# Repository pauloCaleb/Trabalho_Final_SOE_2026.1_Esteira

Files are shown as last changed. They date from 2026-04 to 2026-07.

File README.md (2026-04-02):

## IDENTIFICAÇÃO DOS ESTUDANTES AUTORES
- Felipe de Castro Quixabeira -  231026812
- Paulo Caleb Fernandes da Silva - 211062820 

----
## ORIENTAÇÕES DO PLANO DE ENSINO

#### Projeto Final

Os alunos formarão duplas para montar um projeto final de maior dificuldade, cobrindo os tópicos vistos em sala de aula.

Os projetos serão propostos pelos alunos, e deverá ser apresentado:
- Um protótipo em funcionamento  
- Um relatório no formato científico (formatação IEEE)

#### Estrutura do Relatório

- **Resumo (1 ponto)**  
  Apresentar o projeto de forma geral e em poucas palavras.

- **Introdução (1 ponto)**  
  Descrição do problema a ser resolvido e revisão bibliográfica do assunto.

- **Desenvolvimento (5 pontos)**  
  Solução com justificativa baseada em fundamentos teóricos. Deve conter:

  - **Descrição do hardware (2 pontos)**  
    - BOM (*Bill of Materials*)  
    - Montagem (diagrama de blocos, esquemático e descrição textual)

  - **Descrição do software (3 pontos)**  
    - Apresentação e justificativa do algoritmo desenvolvido  
    - Explicação textual do funcionamento (fluxogramas ou pseudocódigo)  
    - **Importante:** não consiste em replicar o código  
    - O código deve ser incluído como **apêndice**

- **Resultados (2 pontos)**  
  - Experimentos para validar o projeto  
  - Análise crítica dos resultados esperados e obtidos  
  - Discussão de possíveis causas para divergências

- **Conclusão (1 ponto)**  
  Retomar sucintamente:
  - Problema  
  - Solução  
  - Resultados obtidos  

----

### Pontos de Controle (PC)

Os pontos de controle são prévias do projeto final.

> ⚠️ Cada dia de atraso resulta em **-0,5 pontos** na nota do respectivo ponto de controle.

#### PC1 — Proposta do Projeto
- Apresentação do tema escolhido  
- Definição do problema  
- Pesquisa (produtos existentes, artigos, etc.)  
- Texto contendo:
  - Introdução  
  - Justificativa  
  - Objetivos  
  - Requisitos  
  - Benefícios  
  - Revisão bibliográfica  

----

#### PC2 — Funcionamento Básico
- Conectar partes fundamentais ao Raspberry Pi  
  - Exemplos: GPS, sensores, e-mail, câmera, reconhecimento facial  
- Demonstrar funcionamento individual de cada parte  
- Permitido uso de linguagens interpretadas (Python, Octave, etc.)

**Texto:**
- Descrição de hardware  
- Descrição de software  
- Resultados obtidos  

----

#### PC3 — Refinamento do Protótipo
- Conectar todas as partes fundamentais  
- Acrescentar recursos de sistema:
  - Múltiplos processos e threads  
  - Pipes  
  - Sinais  
  - Semáforos  
  - Mutex  

- Desenvolvimento em **C e/ou C++**

**Texto:**
- Atualização de hardware  
- Atualização de software  
- Resultados  

----

#### PC4 — Refinamento Avançado
- Conectar todas as partes fundamentais  
- Acrescentar recursos avançados:
  - Linux em tempo real  

- Desenvolvimento em **C e/ou C++**

**Texto:**
- Atualização de hardware  
- Atualização de software  
- Resultados  

----

### Analogia: Quebra-cabeça

- **PC1:** Escolha do quebra-cabeça  
- **PC2:** Disposição das peças  
- **PC3:** Montagem  
- **PC4:** Montagem (refinamento)  

----

### Observações Importantes

- Todos os relatórios devem ser enviados via **Moodle**  
- Em caso de cópia (total ou parcial):  
  > ❌ Nota **ZERO**

----

### Template IEEE

Disponível em:  
👉 https://www.overleaf.com/read/djkphgstpqsh#36c54d

---
## DOCUMENTO FINAL NO OVERLEAF (em produção)

Link: https://www.overleaf.com/read/gpjtpbhxbqqf#979b82

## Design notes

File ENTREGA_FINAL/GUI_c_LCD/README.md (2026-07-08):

# Esteira Separadora — Guia de Utilização

Sistema de controle em C para **Raspberry Pi 3B**, responsável pela comunicação
com o firmware STM32G070 que governa a esteira separadora via UART.

---

## Requisitos de Hardware

| Componente | Detalhe |
|---|---|
| Raspberry Pi 3B | UART primária habilitada (`/dev/ttyS0`) |
| STM32G070 | Conectado aos pinos GPIO 14 (TX) e 15 (RX) do RPi |
| Câmera USB | Compatível com V4L2, índice 0 = `/dev/video0` |
| Nível lógico | STM32 opera em 3,3 V — mesmo nível do RPi, sem conversor |

> **Atenção:** Desabilite o console serial do RPi antes de usar.
> Caso contrário o Linux usará `/dev/ttyS0` como TTY de console e o
> programa receberá lixo na UART.

---

## Configuração da UART no Raspberry Pi

1. Execute `sudo raspi-config`
2. Acesse **Interface Options → Serial Port**
3. Responda **Não** para "login shell over serial"
4. Responda **Sim** para "serial port hardware enabled"
5. Reinicie o RPi

Verifique que o dispositivo existe:

```bash
ls -l /dev/ttyS0
```

---

## Dependências

```bash
sudo apt update
sudo apt install libopencv-dev libzbar-dev libgpiod-dev
```

---

## Compilação

```bash
make
```

Binário gerado: `./esteira`

Para limpar os objetos:

```bash
make clean
```

---

## Uso

```
./esteira [opções]

  -p <porta>    Porta serial     (padrão: /dev/ttyS0)
  -b <baud>     Baud rate        (padrão: 115200)
  -c <índice>   Índice da câmera (padrão: 0)
  -t <ms>       Timeout QR em ms (padrão: 30000 | 0 = sem limite)
  -m <1|2|3>    Modo direto: 1=FSM, 2=DEBUG, 3=HMI (pula menu interativo)
  -h            Exibe esta ajuda
```

### Exemplos

```bash
# Inicialização padrão — exibe menu de seleção de modo
./esteira

# Modo FSM direto, câmera índice 1, timeout de 20 s
./esteira -m 1 -c 1 -t 20000

# Modo DEBUG direto
./esteira -m 2

# Modo HMI direto (display LCD + botões START/STOP)
./esteira -m 3

# Baud rate diferente (altere também no firmware STM32)
./esteira -b 9600
```

Atalhos do Makefile:

```bash
make run        # compila e abre menu de seleção
make run-fsm    # compila e inicia direto no modo FSM
make run-dbg    # compila e inicia direto no modo DEBUG
make run-hmi    # compila e inicia direto no modo HMI
```

---

## Modos de Operação

### Modo FSM (1) — Operação Autônoma

O programa aguarda eventos do STM32 e responde automaticamente:

```
STM32 → OBJ_DETECTED   Objeto entrou na esteira
STM32 → CLSS_REQUEST   Objeto chegou sob a câmera
RPi   → lê QR code     Classifica destino (Rota A ou B)
RPi   → ROUTE_A_SEND   Envia rota ao STM32
STM32 → ROUTE_A_OK     Confirma entrega — ciclo reinicia
```

Encerre com **Ctrl+C**.

### Modo DEBUG (2) — Controle Manual

Menu interativo no terminal para acionar cada atuador individualmente.
Útil para testes de bancada.

| Tecla | Ação |
|---|---|
| `1` | Flash ON |
| `2` | Flash OFF |
| `3` | Cancela abrir |
| `4` | Cancela fechar |
| `5` | Motor engajar |
| `6` | Motor livre |
| `7` | Direção frente |
| `8` | Direção trás |
| `9` | Enviar N passos |
| `t` | Toggle DEBUG/FSM no STM32 |
| `r` | SW Reset STM32 (pede confirmação) |
| `q` | Sair |

### Modo HMI (3) — Display LCD + Botões START/STOP + Buzzer

Interface física para operação sem terminal: um display LCD 2004A
(I2C) mostra o status da esteira e os contadores de objetos entregues
em cada rota; um botão START e um botão STOP comandam a operação; um
buzzer reforça os alertas visuais do display.

```
[Tela de espera]  "Aperte START"  (mostra contadores A/B)
        │
        ▼ START pressionado
  Inicializa a câmera
        │
        ▼ sucesso
  Handshake com o STM32
        │
        ▼ sucesso
[Operação autônoma — mesma máquina de estados do Modo FSM,
 status + contadores no LCD]
        │
        │  START pressionado durante a operação → zera contadores A/B
        │
        │  falha na leitura do QR → alerta "QR nao identificado /
        │  Libere a esteira!" (backlight + buzzer piscando, sem
        │  timeout) até o operador confirmar com START
        │       │
        │       ▼ START (confirma o alerta)
        │  Reset do STM32 + reenvio do handshake, aguardado sem
        │  timeout fixo (backlight + buzzer continuam piscando)
        │  até o STM32 responder espontaneamente quando os sensores
        │  da esteira ficarem livres
        │       │
        │       ▼ handshake concluído
        │  Retoma a operação autônoma, contadores preservados
        │
        ▼ STOP pressionado (em qualquer estado da operação, inclusive
          durante os alertas acima)
  SW Reset no STM32 + volta para [Tela de espera]
```

O handshake **não** ocorre ao entrar no modo HMI — só é disparado ao
pressionar START, permitindo que o sistema fique ocioso por tempo
indefinido na tela de espera. Ao pressionar START, a câmera é
inicializada primeiro; o handshake com o STM32 só é disparado depois
dela estar pronta, garantindo que a operação autônoma só comece com
todo o hardware necessário já inicializado.

O display mostra, tanto na tela de espera quanto durante a operação,
os contadores de objetos entregues em cada rota (`A:<n> B:<n>`). Eles
persistem entre ciclos e só são zerados ao pressionar **START enquanto
o sistema está em operação**, sem afetar o ciclo em andamento. O botão
**STOP** mantém uma única função: encerrar a operação e voltar à tela
de espera, a partir de qualquer estado.

Se a leitura do QR falhar (timeout ou erro), o display mostra o aviso
"QR nao identificado" e instrui o operador a liberar a esteira; o
backlight e o buzzer piscam em sincronia, sem prazo definido, até o
operador confirmar com START. A confirmação reseta o STM32 e reenvia
o handshake; como o firmware do STM32 só responde ao handshake de
forma espontânea quando os sensores da esteira estão livres, o
Raspberry Pi aguarda essa resposta sem impor um timeout fixo — o
display permanece piscando durante toda a espera, e STOP cancela a
qualquer momento. Se o STM32 responder com erro de protocolo nesse
processo, o programa retorna à tela de espera.

Hardware esperado (ajustável em `hmi.h`):

| Componente | Padrão | Define em hmi.h |
|---|---|---|
| Display LCD 2004A (PCF8574) | `/dev/i2c-1`, endereço `0x27` | `HMI_I2C_DEVICE`, `HMI_LCD_I2C_ADDR` |
| Botão START | `gpiochip0`, linha 17 (GPIO17) | `HMI_BTN_START_LINE` |
| Botão STOP | `gpiochip0`, linha 27 (GPIO27) | `HMI_BTN_STOP_LINE` |
| Buzzer (saída) | `gpiochip0`, linha 23 (GPIO23) | `HMI_BUZZER_LINE` |
| Debounce (software) | 30 ms | `HMI_BTN_DEBOUNCE_MS` |

Os botões usam pull-up **externo** (nível lógico 0 = pressionado); o
GPIO do RPi é configurado sem bias interno para não competir com o
pull-up do circuito. O buzzer é uma saída digital simples (nível 1 =
ligado); se a linha não abrir, o modo HMI segue funcionando
normalmente e os alertas ficam apenas com o backlight piscando.

Ctrl+C encerra o modo HMI a partir de qualquer estado (inclusive
durante os alertas) e exibe no display a mensagem final:

```
PROGRAMA ENCERRADO
Reinicie pelo
terminal
```

Como o controlador HD44780 retém o conteúdo exibido sem energização
contínua, essa mensagem permanece visível no display mesmo após o
processo ser encerrado.

---

## Formato do QR Code

O QR deve conter o campo `Destino:` com o byte de rota em hexadecimal:

```
Nome da Peca: Parafuso M6
Destino: 0xAADA
```

`0xDA` → Rota A  
`0xDB` → Rota B  

O parser também aceita tokens isolados `0xDA` / `0xDB` em qualquer
posição do texto do QR.

---

## Saída no Terminal

Todas as mensagens seguem o formato:

```
HH:MM:SS.mmm  [CATEGORIA]  mensagem
```

| Categoria | Cor | Conteúdo |
|---|---|---|
| `[UART TX]` | Ciano | Frames enviados ao STM32 com bytes hex |
| `[UART RX]` | Verde | Frames recebidos do STM32 com bytes hex |
| `[FSM ]` | Azul | Transições de estado e pipeline visual |
| `[CAM ]` | Magenta | Eventos de câmera e leitura de QR |
| `[DBG ]` | Amarelo | Ações do modo debug |
| `[SYS ]` | Branco | Sistema: serial, threads, handshake |
| `[ERR ]` | Vermelho | Erros de protocolo ou hardware |

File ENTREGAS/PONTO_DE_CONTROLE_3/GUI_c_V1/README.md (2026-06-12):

# Esteira Separadora — Guia de Utilização

Sistema de controle em C para **Raspberry Pi 3B**, responsável pela comunicação
com o firmware STM32G070 que governa a esteira separadora via UART.

---

## Requisitos de Hardware

| Componente | Detalhe |
|---|---|
| Raspberry Pi 3B | UART primária em `/dev/ttyS0` |
| STM32G070 | Conectado aos pinos GPIO 14 (TX) e 15 (RX) do RPi |
| Câmera USB | Compatível com V4L2, índice 0 = `/dev/video0` |
| Nível lógico | STM32 opera em 3,3 V — mesmo nível do RPi, sem conversor |

---

## Dependências

```bash
sudo apt update
sudo apt install libopencv-dev libzbar-dev
```

---

## Compilação

```bash
make
```

Binário gerado: `./esteira`

Para limpar os objetos:

```bash
make clean
```

---

## Uso

```
./esteira [opções]

  -p <porta>    Porta serial     (padrão: /dev/ttyS0)
  -b <baud>     Baud rate        (padrão: 115200)
  -c <índice>   Índice da câmera (padrão: 0)
  -t <ms>       Timeout QR em ms (padrão: 30000 | 0 = sem limite)
  -m <1|2>      Modo direto: 1=FSM, 2=DEBUG (pula menu interativo)
  -h            Exibe esta ajuda
```

### Exemplos

```bash
# Inicialização padrão — exibe menu de seleção de modo
./esteira

# Modo FSM direto, câmera índice 1, timeout de 20 s
./esteira -m 1 -c 1 -t 20000

# Modo DEBUG direto
./esteira -m 2

# Baud rate diferente (altere também no firmware STM32)
./esteira -b 9600
```

Atalhos do Makefile:

```bash
make run        # compila e abre menu de seleção
make run-fsm    # compila e inicia direto no modo FSM
make run-dbg    # compila e inicia direto no modo DEBUG
```

---

## Modos de Operação

### Modo FSM (1) — Operação Autônoma

O programa aguarda eventos do STM32 e responde automaticamente:

```
STM32 → OBJ_DETECTED   Objeto entrou na esteira
STM32 → CLSS_REQUEST   Objeto chegou sob a câmera
RPi   → lê QR code     Classifica destino (Rota A ou B)
RPi   → ROUTE_A_SEND   Envia rota ao STM32
STM32 → ROUTE_A_OK     Confirma entrega — ciclo reinicia
```

Encerre com **Ctrl+C**.

### Modo DEBUG (2) — Controle Manual

Menu interativo no terminal para acionar cada atuador individualmente.
Útil para testes de bancada.

| Tecla | Ação |
|---|---|
| `1` | Flash ON |
| `2` | Flash OFF |
| `3` | Cancela abrir |
| `4` | Cancela fechar |
| `5` | Motor engajar |
| `6` | Motor livre |
| `7` | Direção frente |
| `8` | Direção trás |
| `9` | Enviar N passos |
| `t` | Toggle DEBUG/FSM no STM32 |
| `r` | SW Reset STM32 (pede confirmação) |
| `q` | Sair |

---

## Formato do QR Code

O QR deve conter o campo `Destino:` com o byte de rota em hexadecimal:

```
Nome da Peca: Parafuso M6
Destino: 0xAADA
```

`0xDA` → Rota A  
`0xDB` → Rota B  

O parser também aceita tokens isolados `0xDA` / `0xDB` em qualquer
posição do texto do QR.

---

## Saída no Terminal

Todas as mensagens seguem o formato:

```
HH:MM:SS.mmm  [CATEGORIA]  mensagem
```

| Categoria | Cor | Conteúdo |
|---|---|---|
| `[UART TX]` | Ciano | Frames enviados ao STM32 com bytes hex |
| `[UART RX]` | Verde | Frames recebidos do STM32 com bytes hex |
| `[FSM ]` | Azul | Transições de estado e pipeline visual |
| `[CAM ]` | Magenta | Eventos de câmera e leitura de QR |
| `[DBG ]` | Amarelo | Ações do modo debug |
| `[SYS ]` | Branco | Sistema: serial, threads, handshake |
| `[ERR ]` | Vermelho | Erros de protocolo ou hardware |

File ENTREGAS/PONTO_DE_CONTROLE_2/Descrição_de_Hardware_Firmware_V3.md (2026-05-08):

# Relatório Parcial — Esteira Separadora (Firmware v3.0)
**Sistemas Operacionais Embarcados (SOE) — 2026.1**
**Autores:** Paulo Caleb Fernandes da Silva, Felipe de Castro

---

## 1. Descrição do Hardware Controlado

O sistema é composto por uma arquitetura híbrida que divide as responsabilidades entre um microprocessador de alto nível e um microcontrolador dedicado ao controle direto dos dispositivos físicos da esteira.

O **Raspberry Pi 3B** atua como o processador de alto nível, sendo responsável por executar os algoritmos de visão computacional para leitura de QR codes e classificação dos objetos transportados. Uma webcam USB acoplada ao Raspberry Pi captura as imagens no momento adequado do ciclo de operação. As decisões de roteamento são transmitidas ao microcontrolador via comunicação serial UART.

O **STM32G070** é o microcontrolador responsável pelo controle direto dos atuadores e pela leitura dos sensores. Opera a uma frequência de CPU de 64 MHz, obtida por meio do PLL interno a partir do oscilador HSI de 16 MHz (PLLN = 8, PLLM = 1, PLLR = 2). Os periféricos utilizados estão detalhados a seguir.

| Timer | Função |
|---|---|
| TIM15 | PWM fixo de 200 Hz para modulação dos lasers |
| TIM3  | Input Capture + DMA para medição de frequência dos 4 sensores |
| TIM16 | PWM de duty variável (50 Hz) para controle do servo motor |
| TIM6  | Base de tempo de 1 µs para controle do motor de passo via interrupção |

A **USART2** é configurada a 115200 bps, 8N1, sem controle de fluxo por hardware, para a comunicação serial com o Raspberry Pi 3B.

---

## 2. Sensores Laser — Detecção Síncrona por Portadora

Os quatro sensores laser operam sobre o princípio da **detecção síncrona por ausência de portadora**. O TIM15 gera um sinal PWM de 200 Hz com duty cycle de 50% (CCR = 25, ARR = 49, prescaler = 6399 sobre 64 MHz), que modula o acionamento dos transmissores laser. O receptor de cada sensor entrega ao STM32 um sinal digital pulsado nessa mesma frequência enquanto o feixe estiver livre.

A medição é feita pelo **TIM3 em modo Input Capture com DMA** (prescaler = 63, ARR = 65535, base de tempo = 1 µs/tick). Dois valores de captura consecutivos na borda de descida são armazenados em um vetor de dois elementos por DMA. A diferença entre as capturas fornece o período do sinal, e a frequência é calculada como:

```
SENSn_freq = 1.000.000 / SENSn_capture   [Hz]
```

Quando um objeto interrompe o feixe, a portadora desaparece e a diferença de captura torna-se zero. Nesse caso, `SENSn_flag` é setada em `1` (objeto detectado) e `SENSn_freq` é zerada. O período de amostragem é controlado por `sensUPDT = 10 ms`, que deve ser pelo menos o dobro do período do sinal da portadora (5 ms), garantindo duas bordas capturáveis por ciclo.

A frequência esperada de 200 Hz em todos os quatro sensores é verificada durante o procedimento de inicialização para confirmar que os feixes estão livres e os sensores operacionais antes que o handshake com o Raspberry Pi seja aceito.

---

## 3. Servo Motor

O servo motor ES08MA é controlado pelo **TIM16** em modo PWM (prescaler = 63, ARR = 19999, base de tempo = 1 µs/tick, período total = 20 ms = 50 Hz). O mapeamento de ângulo para largura de pulso é realizado pela função `SetServoAngle()`:

```
pulse_length = SERVO_MIN_US + (angle × (SERVO_MAX_US − SERVO_MIN_US) / SERVO_MAX_ANGLE)
```

onde `SERVO_MIN_US = 600 µs`, `SERVO_MAX_US = 2300 µs` e `SERVO_MAX_ANGLE = 180°`. O valor calculado é carregado diretamente no registrador CCR do TIM16.

Na aplicação, dois ângulos são utilizados: `closeAngle = 0°` (cancela fechada, rota A) e `openAngle = 45°` (cancela aberta, rota B).

---

## 4. Motor de Passo

O motor de passo é acionado por um driver **A4988** e controlado pelo **TIM6** (prescaler = 63, ARR variável, base de tempo = 1 µs/tick). A velocidade é ajustada pela função `stepperSetSpeed()`, que recalcula o ARR conforme:

```
TIM6_intFreq = 2 × steppsPerSeconds
newARR = (TIM6_FREQUENCY / TIM6_intFreq) − 1
```

O fator 2 é necessário porque a ISR alterna o pino STEP a cada interrupção (toggle), de modo que um pulso completo (borda de subida + descida) corresponde a dois eventos de interrupção. A velocidade é limitada entre `STEPPER_MIN_VEL = 300 passos/s` e `STEPPER_MAX_VEL = 420 passos/s`.

A ISR `STEPPER_TIM6_ISR()`, chamada pelo callback `HAL_TIM_PeriodElapsedCallback()`, executa a lógica de contagem de passos:

1. Se `stepperEN == 1` e `targetStepps > 0`: alterna o pino STEP; quando `pulse_ctrl == 1` (borda de subida), decrementa `targetStepps`.
2. Se `targetStepps == 0`: força o pino STEP em nível baixo e seta `movement_done_flag = 1`.

A variável `pulse_ctrl` inverte a cada ISR, garantindo que o decremento ocorra somente uma vez por pulso completo.

Três modos de parada estão implementados:

- `stepperStopDisengaged()`: desliga o driver A4988 (pino SLEEP em nível baixo), libera o eixo.
- `stepperStopEngaged()`: mantém o driver energizado (pino SLEEP em nível alto), trava o eixo.
- `stepperFollowSteps()`: habilita o driver, reseta os controles e ativa o TIM6 para retomar a geração de pulsos.

Na FSM, o motor solicita continuamente `stepperMove(350, 0)` (350 passos para frente) nos estados que requerem movimento, garantindo que a esteira não pare enquanto o objeto estiver em trânsito.

---

## 5. Protocolo de Comunicação UART

A comunicação entre o STM32 e o Raspberry Pi 3B é realizada por quadros binários estruturados sobre a USART2 (115200 bps, 8N1). A recepção é feita em modo **interrupt-driven** (`HAL_UART_Receive_IT`, 1 byte por vez), processada por uma máquina de estados de três estágios no callback `HAL_UART_RxCpltCallback()`.

### 5.1 Estrutura dos Quadros

**Quadro RX (Raspberry Pi → STM32):**

| Byte 0 | Byte 1 | Byte 2 (opcional) |
|:---:|:---:|:---:|
| `0xAA` START | CMD | DATA |

O byte DATA só está presente quando `CMD = 0xE5` (`SET_STPR_TGT_STPS_MSG`), que carrega a quantidade de passos como argumento.

**Quadro TX (STM32 → Raspberry Pi):**

| Tipo | Byte 0 | Byte 1 | Byte 2 (opcional) |
|:---:|:---:|:---:|:---:|
| Confirmação / Msg  | `0x90` | payload/eco  | — |
| Erro | `0x91` | — | — |
| Telemetria | `0x90` | `0x55` | STATUS_BYTE |

### 5.2 Tabela de Comandos

| Categoria | Byte  | Identificador | Direção | Descrição |
|---|:-----:|---|:---:|---|
| Handshake | `0x10`| `SYS_RDY_MSG` | RBPi3 → STM32 | Sinaliza que o RBPi3 está pronto |
| Handshake | `0x01`| `SYS_INIT_MSG` | STM32 → RBPi3 | Confirma inicialização do sistema |
| FSM RX | `0xDA`| `ROUTE_A_RECEIVE_MSG` | RBPi3 → STM32 | Encaminha objeto para a Rota A |
| FSM RX | `0xDB`| `ROUTE_B_RECEIVE_MSG` | RBPi3 → STM32 | Encaminha objeto para a Rota B |
| FSM TX | `0xA0`| `OBJ_DETECTED_MSG` | STM32 → RBPi3 | Objeto detectado no sensor 1 |
| FSM TX | `0xC0`| `CLSS_REQUEST_MSG` | STM32 → RBPi3 | Objeto sob a câmera, solicita classificação |
| FSM TX | `0xFA`| `ROUTE_A_FWRDNG_MSG` | STM32 → RBPi3 | Confirmação de encaminhamento para Rota A |
| FSM TX | `0xFB`| `ROUTE_B_FWRDNG_MSG` | STM32 → RBPi3 | Confirmação de encaminhamento para Rota B |
| FSM TX | `0xBA`| `ROUTE_A_SCCSS_DLVRY_MSG`| STM32 → RBPi3  | Entrega confirmada na Rota A |
| FSM TX | `0xBB`| `ROUTE_B_SCCSS_DLVRY_MSG`| STM32 → RBPi3  | Entrega confirmada na Rota B |
| Controle async | `0xE1`| `LIGHT_EN_MSG` | RBPi3 → STM32 | Liga o flash |
| Controle async | `0xD1`| `LIGHT_DISABLE_MSG` | RBPi3 → STM32 | Desliga o flash |
| Controle async | `0xE2`| `GATE_OPEN_MSG` | RBPi3 → STM32 | Abre a cancela (servo) |
| Controle async | `0xD2`| `GATE_CLOSE_MSG` | RBPi3 → STM32 | Fecha a cancela (servo) |
| Controle async | `0xE3`| `STPR_EN_MSG` | RBPi3 → STM32 | Engaja o motor de passo |
| Controle async | `0xD3`| `STPR_DISABLE_MSG` | RBPi3 → STM32 | Libera o motor de passo |
| Controle async | `0xE4`| `SET_STPR_FORWARD_MSG`  | RBPi3 → STM32 | Define direção: frente |
| Controle async | `0xD4`| `SET_STPR_BACKWARD_MSG` | RBPi3 → STM32 | Define direção: trás |
| Controle async | `0xE5`| `SET_STPR_TGT_STPS_MSG` | RBPi3 → STM32 | Define nº de passos (DATA = valor) |
| Modo | `0xDD`| `DEBUG_MODE_TOGGLE_MSG` | RBPi3 → STM32 | Alterna entre modo FSM e Debug |
| Modo | `0x11`| `MODE_FSM_MSG` | STM32 → RBPi3 | Informa modo FSM ativo |
| Modo | `0x22`| `MODE_DEBUG_MSG` | STM32 → RBPi3 | Informa modo Debug ativo |
| Controle | `0x33`| `SW_RESET_MSG` | RBPi3 → STM32 | Solicita reset por software (NVIC) |
| Telemetria | `0x55`| `SENS_STATUS_MSG` | STM32 → RBPi3 | Envia STATUS_BYTE dos 4 sensores |
| Resposta | `0x90`| `CMD_OK_MSG` | STM32 → RBPi3 | Confirmação positiva |
| Resposta | `0x91`| `CMD_ERR_MSG` | STM32 → RBPi3 | Erro de reconhecimento |

### 5.3 Parser RX — Máquina de Estados

A recepção de quadros é gerenciada por uma FSM de três estados na ISR de recepção UART:

```
RX_WAIT_START  →  byte == 0xAA  →  RX_WAIT_CMD
RX_WAIT_CMD    →  CMD != 0xE5   →  frame completo (2 bytes) → RX_WAIT_START
RX_WAIT_CMD    →  CMD == 0xE5   →  RX_WAIT_DATA
RX_WAIT_DATA   →                →  frame completo (3 bytes) → RX_WAIT_START
```

Qualquer byte fora de frame recebido no estado `RX_WAIT_START` é silenciosamente descartado, protegendo o parser contra ruído ou dados espúrios no barramento.

O frame completo é sinalizado pela flag `rxFrameReady`, com o comando em `rxCMD` e o dado opcional em `rxDATA`.

### 5.4 Transmissão TX

As funções de transmissão são:

- `sendFrame(status, payload)`: envia 2 bytes `[status][payload]`. Se `status == 0x91` (CMD_ERR), envia apenas 1 byte.
- `telemetryFrame(status, cmd, data)`: envia 3 bytes `[0x90][0x55][STATUS_BYTE]`.

As mensagens espontâneas da FSM são enviadas por flags no loop principal (ex.: `objDetectedMSG_flag`, `classificationRequestMSG_flag`), evitando chamadas de transmissão dentro da ISR.

### 5.5 Telemetria de Sensores

A função `sendTelemetryData()` opera exclusivamente no **modo Debug** e monta o `STATUS_BYTE` com as flags dos quatro sensores nos bits 0 a 3:

```
STATUS_BYTE = SENS1_flag | (SENS2_flag << 1) | (SENS3_flag << 2) | (SENS4_flag << 3)
```

A transmissão só ocorre quando o `STATUS_BYTE` muda em relação ao valor anterior (`sensStatusByteLast`), evitando flood no barramento UART. O valor inicial de `sensStatusByteLast` é `0xFF`, forçando o envio na primeira iteração.

---

## 6. Modos de Operação

O firmware opera em dois modos selecionáveis pelo comando `DEBUG_MODE_TOGGLE_MSG (0xDD)`:

| Modo | Valor | Descrição |
|---|:-----:|---|
| `OP_MODE_FSM` | 0 | Modo normal: FSM completa em execução, telemetria desativada |
| `OP_MODE_DEBUG` | 1 | Modo debug: FSM suspensa, apenas comandos assíncronos e telemetria |

A troca de modo é processada pela função `handleModeToggle()`, chamada no início de cada iteração do loop principal, com prioridade sobre as demais funções. Ao entrar no modo Debug, o motor é travado (`stepperStopEngaged()`), o flash é apagado e um padrão de pisca no LED de debug confirma a transição. Ao retornar ao modo FSM, o estado é redefinido para `STATE_IDLE` e `last_state` para `STATE_NONE`, forçando a execução das entry actions.

O comando `SW_RESET_MSG (0x33)` provoca um reset por software via `NVIC_SystemReset()`, com um delay de 50 ms para garantir que o frame de confirmação seja transmitido antes do reset.

---

## 7. Máquina de Estados Finitos (FSM)

A FSM principal da aplicação é implementada na função `FSM()`, chamada no loop principal somente quando `operationMode == OP_MODE_FSM`. O padrão utilizado separa explicitamente as **entry actions** (executadas uma única vez na transição de estado) das **actions de estado** (executadas a cada iteração).

A condição de entrada é verificada por `state != last_state`. Ao executar a entry action, `last_state` é igualado a `state`, fechando a condição.

### 7.1 Descrição dos Estados

**`STATE_IDLE` (0):** Estado inicial e de repouso. O flash é desligado, a cancela é fechada (`SetServoAngle(0)`) e o motor é habilitado em modo follow-steps. A cada iteração, é solicitado um movimento de 350 passos. A transição ocorre quando `SENS1_flag == 1` (objeto detectado na entrada da esteira), momento em que `objDetectedMSG_flag` é setada para notificar o Raspberry Pi.

**`STATE_OBJECT_DETECTED` (1):** O motor continua em movimento (350 passos por iteração). A transição ocorre quando `SENS2_flag == 1` (objeto sob a câmera), momento em que `classificationRequestMSG_flag` é setada, solicitando ao Raspberry Pi que realize a leitura do QR code e envie o destino.

**`STATE_WAIT_CLASSIFICATION` (2):** O flash é ligado para iluminar a cena de captura e o motor é parado com o eixo travado (`stepperStopEngaged()`). O firmware aguarda o recebimento de `ROUTE_A_RECEIVE_MSG (0xDA)` ou `ROUTE_B_RECEIVE_MSG (0xDB)`. Ao receber o destino, o frame é confirmado com `CMD_OK` e a flag de encaminhamento correspondente é setada.

**`STATE_ROUTE_A` (3):** A cancela é mantida fechada (`SetServoAngle(closeAngle)`), o flash é desligado e o motor retoma o movimento. A transição ocorre quando `SENS3_flag == 1` (objeto saiu pela Rota A), setando `routeASuccesDeliveryMSG_flag` e retornando a `STATE_IDLE`.

**`STATE_ROUTE_B` (4):** A cancela é aberta (`SetServoAngle(openAngle)`), o flash é desligado e o motor retoma o movimento. A transição ocorre quando `SENS4_flag == 1` (objeto saiu pela Rota B), setando `routeBSuccesDeliveryMSG_flag` e retornando a `STATE_IDLE`.

---

## 8. Procedimento de Inicialização e Handshake

Antes de entrar no loop principal, o firmware executa uma rotina de inicialização que bloqueia até que duas condições sejam satisfeitas:

1. **Todos os quatro sensores operacionais:** `SENS1_freq == 200 && SENS2_freq == 200 && SENS3_freq == 200 && SENS4_freq == 200`. Enquanto isso não ocorre, o LED de debug pisca rapidamente (100 ms).

2. **Handshake com o Raspberry Pi:** o STM32 aguarda receber `[0xAA][0x10]` (`SYS_RDY_MSG`). Após receber os sensores prontos + o handshake, responde com `[0x90][0x01]` (`SYS_INIT_MSG`) seguido de `[0x90][0x11]` (`MODE_FSM_MSG`), informando o modo de operação inicial. Enquanto aguarda o handshake com os sensores já prontos, o LED pisca lentamente (500 ms).

---

## 9. Controle Assíncrono (Modo Debug)

No modo Debug, a função `handleAsyncCommands()` processa os comandos recebidos para controle individual dos periféricos:

| Comando | Ação |
|---|---|
| `LIGHT_EN (0xE1)` | Liga o pino FLASH_PIN |
| `LIGHT_DISABLE (0xD1)`| Desliga o pino FLASH_PIN |
| `GATE_OPEN (0xE2)` | `SetServoAngle(openAngle)` |
| `GATE_CLOSE (0xD2)` | `SetServoAngle(closeAngle)` |
| `STPR_EN (0xE3)` | `stepperFollowSteps()` |
| `STPR_DISABLE (0xD3)` | `stepperStopDisengaged()` |
| `STPR_FORWARD (0xE4)` | Define `stepperDirInst = 0` |
| `STPR_BACKWARD (0xD4)`| Define `stepperDirInst = 1` |
| `STPR_TGT_STPS (0xE5)`| `targetStepps = rxDATA` |

Cada comando recebe uma confirmação `[0x90][CMD_eco]`. Comandos não reconhecidos retornam `[0x91]`.

---

## 10. Resumo das GPIOs

| Pino | Direção | Função |
|---|:---:|---|
| DIR  | Saída | Direção do motor de passo (A4988) |
| STEP | Saída | Pulsos de passo (A4988) |
| SLEEP| Saída | Enable/Sleep do driver A4988 |
| dbgLED | Saída | LED de diagnóstico |
| FLASH_PIN | Saída | Acionamento do flash de iluminação |

---

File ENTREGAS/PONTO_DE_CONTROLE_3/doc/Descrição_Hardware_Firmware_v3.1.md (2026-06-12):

# Relatório Parcial — Esteira Separadora (Firmware v3.1)
**Sistemas Operacionais Embarcados (SOE) — 2026.1**
**Autores:** Paulo Caleb Fernandes da Silva, Felipe de Castro

---

## 1. Descrição do Hardware Controlado

O sistema é composto por uma arquitetura híbrida que divide as responsabilidades entre um microprocessador de alto nível e um microcontrolador dedicado ao controle direto dos dispositivos físicos da esteira.

O **Raspberry Pi 3B** atua como o processador de alto nível, sendo responsável por executar os algoritmos de visão computacional para leitura de QR codes e classificação dos objetos transportados. Uma webcam USB acoplada ao Raspberry Pi captura as imagens no momento adequado do ciclo de operação. As decisões de roteamento são transmitidas ao microcontrolador via comunicação serial UART.

O **STM32G070** é o microcontrolador responsável pelo controle direto dos atuadores e pela leitura dos sensores. Opera a uma frequência de CPU de 64 MHz, obtida por meio do PLL interno a partir do oscilador HSI de 16 MHz (PLLN = 8, PLLM = 1, PLLR = 2). Os periféricos utilizados estão detalhados a seguir.

| Timer | Função |
|---|---|
| TIM15 | PWM fixo de 200 Hz para modulação dos lasers |
| TIM3  | Input Capture + DMA para medição de frequência dos 4 sensores |
| TIM16 | PWM de duty variável (50 Hz) para controle do servo motor |
| TIM6  | Base de tempo de 1 µs para controle do motor de passo via interrupção |
| TIM17 | PWM de brilho variável para o flash (fade-in/fade-out) — **novo em v3.1** |

A **USART2** é configurada a 115200 bps, 8N1, sem controle de fluxo por hardware, para a comunicação serial com o Raspberry Pi 3B.

---

## 2. Sensores Laser — Detecção Síncrona por Portadora

Os quatro sensores laser operam sobre o princípio da **detecção síncrona por ausência de portadora**. O TIM15 gera um sinal PWM de 200 Hz com duty cycle de 50% (CCR = 25, ARR = 49, prescaler = 6399 sobre 64 MHz), que modula o acionamento dos transmissores laser. O receptor de cada sensor entrega ao STM32 um sinal digital pulsado nessa mesma frequência enquanto o feixe estiver livre.

A medição é feita pelo **TIM3 em modo Input Capture com DMA** (prescaler = 63, ARR = 65535, base de tempo = 1 µs/tick). Dois valores de captura consecutivos na borda de descida são armazenados em um vetor de dois elementos por DMA. A diferença entre as capturas fornece o período do sinal, e a frequência é calculada como:

```
SENSn_freq = 1.000.000 / SENSn_capture   [Hz]
```

Quando um objeto interrompe o feixe, a portadora desaparece e a diferença de captura torna-se zero. Nesse caso, `SENSn_flag` é setada em `1` (objeto detectado) e `SENSn_freq` é zerada. O período de amostragem é controlado por `sensUPDT = 10 ms`, que deve ser pelo menos o dobro do período do sinal da portadora (5 ms), garantindo duas bordas capturáveis por ciclo.

A frequência esperada de 200 Hz em todos os quatro sensores é verificada durante o procedimento de inicialização para confirmar que os feixes estão livres e os sensores operacionais antes que o handshake com o Raspberry Pi seja aceito.

---

## 3. Servo Motor

O servo motor ES08MA é controlado pelo **TIM16** em modo PWM (prescaler = 63, ARR = 19999, base de tempo = 1 µs/tick, período total = 20 ms = 50 Hz). O mapeamento de ângulo para largura de pulso é realizado pela função `SetServoAngle()`:

```
pulse_length = SERVO_MIN_US + (angle × (SERVO_MAX_US − SERVO_MIN_US) / SERVO_MAX_ANGLE)
```

onde `SERVO_MIN_US = 600 µs`, `SERVO_MAX_US = 2300 µs` e `SERVO_MAX_ANGLE = 180°`. O valor calculado é carregado diretamente no registrador CCR do TIM16.

Na aplicação, dois ângulos são utilizados: `closeAngle = 0°` (cancela fechada, rota A) e `openAngle = 45°` (cancela aberta, rota B).

---

## 4. Motor de Passo

O motor de passo é acionado por um driver **A4988** e controlado pelo **TIM6** (prescaler = 63, ARR variável, base de tempo = 1 µs/tick). A velocidade é ajustada pela função `stepperSetSpeed()`, que recalcula o ARR conforme:

```
TIM6_intFreq = 2 × steppsPerSeconds
newARR = (TIM6_FREQUENCY / TIM6_intFreq) − 1
```

O fator 2 é necessário porque a ISR alterna o pino STEP a cada interrupção (toggle), de modo que um pulso completo (borda de subida + descida) corresponde a dois eventos de interrupção. A velocidade é limitada entre `STEPPER_MIN_VEL = 300 passos/s` e `STEPPER_MAX_VEL = 420 passos/s`.

A ISR `STEPPER_TIM6_ISR()`, chamada pelo callback `HAL_TIM_PeriodElapsedCallback()`, executa a lógica de contagem de passos:

1. Se `stepperEN == 1` e `targetStepps > 0`: alterna o pino STEP; quando `pulse_ctrl == 1` (borda de subida), decrementa `targetStepps`.
2. Se `targetStepps == 0`: força o pino STEP em nível baixo e seta `movement_done_flag = 1`.

A variável `pulse_ctrl` inverte a cada ISR, garantindo que o decremento ocorra somente uma vez por pulso completo.

Três modos de parada estão implementados:

- `stepperStopDisengaged()`: desliga o driver A4988 (pino SLEEP em nível baixo), libera o eixo.
- `stepperStopEngaged()`: mantém o driver energizado (pino SLEEP em nível alto), trava o eixo.
- `stepperFollowSteps()`: habilita o driver, reseta os controles e ativa o TIM6 para retomar a geração de pulsos.

Na FSM, o motor solicita continuamente `stepperMove(350, 0)` (350 passos para frente) nos estados que requerem movimento, garantindo que a esteira não pare enquanto o objeto estiver em trânsito.

---

## 5. Flash de Iluminação — PWM com Sweep (TIM17) *(novo em v3.1)*

A versão 3.1 substitui o acionamento direto por GPIO do flash por um controle via **PWM com efeito fade-in/fade-out**, implementado no **TIM17** (prescaler = 63, ARR = 999, base de tempo = 1 µs/tick, frequência de chaveamento = 1 kHz).

### 5.1 Parâmetros de Configuração

| Define | Valor | Descrição |
|---|:-----:|---|
| `FLASH_SWEEP_MIN` | 50 | Duty cycle mínimo (brilho mínimo, ~5%) |
| `FLASH_SWEEP_MAX` | 950 | Duty cycle máximo (brilho máximo, ~95%) |
| `FLASH_SWEEP_STEP` | 10 | Incremento de duty por passo (velocidade do fade) |
| `FLASH_SWEEP_PERIOD` | 20 ms | Intervalo entre passos (cadência do sweep) |

### 5.2 Funções de Controle

**`flashPWM_Start()`** — chamada no entry action de `STATE_WAIT_CLASSIFICATION`:
- Reinicia `flashSweep_duty` para `FLASH_SWEEP_MIN` e `flashSweep_dir` para `+1` (sentido crescente).
- Registra o tick atual em `flashSweep_lastTick`.
- Carrega o duty inicial no CCR do TIM17 e inicia o PWM via `HAL_TIM_PWM_Start()`.

**`flashPWM_Stop()`** — chamada nos entry actions de `STATE_ROUTE_A`, `STATE_ROUTE_B` e `STATE_IDLE`, e ao entrar no modo Debug:
- Para o PWM via `HAL_TIM_PWM_Stop()`.
- Força o pino `FLASH_PWM_Pin` em nível baixo com `HAL_GPIO_WritePin()`, garantindo que o LED não fique aceso por resíduo do PWM.

**`flashPWM_Sweep()`** — chamada iterativamente no corpo do estado `STATE_WAIT_CLASSIFICATION`:
- Verifica a base de tempo própria (`FLASH_SWEEP_PERIOD`), retornando imediatamente se o intervalo não tiver decorrido. Isso torna a função independente da velocidade do loop principal.
- Calcula o próximo duty: `next = flashSweep_duty + flashSweep_dir × FLASH_SWEEP_STEP`.
- Aplica saturação nos limites `FLASH_SWEEP_MAX` e `FLASH_SWEEP_MIN`, invertendo `flashSweep_dir` ao atingir cada extremo.
- Atualiza `flashSweep_duty` e carrega o novo valor no CCR: `__HAL_TIM_SET_COMPARE(&htim17, TIM_CHANNEL_1, flashSweep_duty)`.

### 5.3 Comportamento no Modo Debug

No modo Debug, o comando `LIGHT_EN (0xE1)` liga o flash com duty fixo máximo (`FLASH_SWEEP_MAX`), sem ativar o sweep:

```c
HAL_TIM_PWM_Start(&htim17, TIM_CHANNEL_1);
__HAL_TIM_SET_COMPARE(&htim17, TIM_CHANNEL_1, FLASH_SWEEP_MAX);
```

O comando `LIGHT_DISABLE (0xD1)` chama `flashPWM_Stop()`, desligando o PWM e forçando o pino em nível baixo.

---

## 6. Protocolo de Comunicação UART

A comunicação entre o STM32 e o Raspberry Pi 3B é realizada por quadros binários estruturados sobre a USART2 (115200 bps, 8N1). A recepção é feita em modo **interrupt-driven** (`HAL_UART_Receive_IT`, 1 byte por vez), processada por uma máquina de estados de três estágios no callback `HAL_UART_RxCpltCallback()`.

### 6.1 Estrutura dos Quadros

**Quadro RX (Raspberry Pi → STM32):**

| Byte 0 | Byte 1 | Byte 2 (opcional) |
|:---:|:---:|:---:|
| `0xAA` START | CMD | DATA |

O byte DATA só está presente quando `CMD = 0xE5` (`SET_STPR_TGT_STPS_MSG`), que carrega a quantidade de passos como argumento.

**Quadro TX (STM32 → Raspberry Pi):**

| Tipo | Byte 0 | Byte 1 | Byte 2 (opcional) |
|:---:|:---:|:---:|:---:|
| Confirmação / Msg  | `0x90` | payload/eco  | — |
| Erro | `0x91` | — | — |
| Telemetria | `0x90` | `0x55` | STATUS_BYTE |

### 6.2 Tabela de Comandos

| Categoria | Byte  | Identificador | Direção | Descrição |
|---|:-----:|---|:---:|---|
| Handshake | `0x10`| `SYS_RDY_MSG` | RBPi3 → STM32 | Sinaliza que o RBPi3 está pronto |
| Handshake | `0x01`| `SYS_INIT_MSG` | STM32 → RBPi3 | Confirma inicialização do sistema |
| FSM RX | `0xDA`| `ROUTE_A_RECEIVE_MSG` | RBPi3 → STM32 | Encaminha objeto para a Rota A |
| FSM RX | `0xDB`| `ROUTE_B_RECEIVE_MSG` | RBPi3 → STM32 | Encaminha objeto para a Rota B |
| FSM TX | `0xA0`| `OBJ_DETECTED_MSG` | STM32 → RBPi3 | Objeto detectado no sensor 1 |
| FSM TX | `0xC0`| `CLSS_REQUEST_MSG` | STM32 → RBPi3 | Objeto sob a câmera, solicita classificação |
| FSM TX | `0xFA`| `ROUTE_A_FWRDNG_MSG` | STM32 → RBPi3 | Confirmação de encaminhamento para Rota A |
| FSM TX | `0xFB`| `ROUTE_B_FWRDNG_MSG` | STM32 → RBPi3 | Confirmação de encaminhamento para Rota B |
| FSM TX | `0xBA`| `ROUTE_A_SCCSS_DLVRY_MSG`| STM32 → RBPi3  | Entrega confirmada na Rota A |
| FSM TX | `0xBB`| `ROUTE_B_SCCSS_DLVRY_MSG`| STM32 → RBPi3  | Entrega confirmada na Rota B |
| Controle async | `0xE1`| `LIGHT_EN_MSG` | RBPi3 → STM32 | Liga o flash (duty fixo máximo) |
| Controle async | `0xD1`| `LIGHT_DISABLE_MSG` | RBPi3 → STM32 | Desliga o flash |
| Controle async | `0xE2`| `GATE_OPEN_MSG` | RBPi3 → STM32 | Abre a cancela (servo) |
| Controle async | `0xD2`| `GATE_CLOSE_MSG` | RBPi3 → STM32 | Fecha a cancela (servo) |
| Controle async | `0xE3`| `STPR_EN_MSG` | RBPi3 → STM32 | Engaja o motor de passo |
| Controle async | `0xD3`| `STPR_DISABLE_MSG` | RBPi3 → STM32 | Libera o motor de passo |
| Controle async | `0xE4`| `SET_STPR_FORWARD_MSG`  | RBPi3 → STM32 | Define direção: frente |
| Controle async | `0xD4`| `SET_STPR_BACKWARD_MSG` | RBPi3 → STM32 | Define direção: trás |
| Controle async | `0xE5`| `SET_STPR_TGT_STPS_MSG` | RBPi3 → STM32 | Define nº de passos (DATA = valor) |
| Modo | `0xDD`| `DEBUG_MODE_TOGGLE_MSG` | RBPi3 → STM32 | Alterna entre modo FSM e Debug |
| Modo | `0x11`| `MODE_FSM_MSG` | STM32 → RBPi3 | Informa modo FSM ativo |
| Modo | `0x22`| `MODE_DEBUG_MSG` | STM32 → RBPi3 | Informa modo Debug ativo |
| Controle | `0x33`| `SW_RESET_MSG` | RBPi3 → STM32 | Solicita reset por software (NVIC) |
| Telemetria | `0x55`| `SENS_STATUS_MSG` | STM32 → RBPi3 | Envia STATUS_BYTE dos 4 sensores |
| Resposta | `0x90`| `CMD_OK_MSG` | STM32 → RBPi3 | Confirmação positiva |
| Resposta | `0x91`| `CMD_ERR_MSG` | STM32 → RBPi3 | Erro de reconhecimento |

### 6.3 Parser RX — Máquina de Estados

A recepção de quadros é gerenciada por uma FSM de três estados na ISR de recepção UART:

```
RX_WAIT_START  →  byte == 0xAA  →  RX_WAIT_CMD
RX_WAIT_CMD    →  CMD != 0xE5   →  frame completo (2 bytes) → RX_WAIT_START
RX_WAIT_CMD    →  CMD == 0xE5   →  RX_WAIT_DATA
RX_WAIT_DATA   →                →  frame completo (3 bytes) → RX_WAIT_START
```

Qualquer byte fora de frame recebido no estado `RX_WAIT_START` é silenciosamente descartado, protegendo o parser contra ruído ou dados espúrios no barramento.

O frame completo é sinalizado pela flag `rxFrameReady`, com o comando em `rxCMD` e o dado opcional em `rxDATA`.

### 6.4 Transmissão TX

As funções de transmissão são:

- `sendFrame(status, payload)`: envia 2 bytes `[status][payload]`. Se `status == 0x91` (CMD_ERR), envia apenas 1 byte.
- `telemetryFrame(status, cmd, data)`: envia 3 bytes `[0x90][0x55][STATUS_BYTE]`.

As mensagens espontâneas da FSM são enviadas por flags no loop principal (ex.: `objDetectedMSG_flag`, `classificationRequestMSG_flag`), evitando chamadas de transmissão dentro da ISR.

### 6.5 Telemetria de Sensores

A função `sendTelemetryData()` opera exclusivamente no **modo Debug** e monta o `STATUS_BYTE` com as flags dos quatro sensores nos bits 0 a 3:

```
STATUS_BYTE = SENS1_flag | (SENS2_flag << 1) | (SENS3_flag << 2) | (SENS4_flag << 3)
```

A transmissão só ocorre quando o `STATUS_BYTE` muda em relação ao valor anterior (`sensStatusByteLast`), evitando flood no barramento UART. O valor inicial de `sensStatusByteLast` é `0xFF`, forçando o envio na primeira iteração.

---

## 7. Modos de Operação

O firmware opera em dois modos selecionáveis pelo comando `DEBUG_MODE_TOGGLE_MSG (0xDD)`:

| Modo | Valor | Descrição |
|---|:-----:|---|
| `OP_MODE_FSM` | 0 | Modo normal: FSM completa em execução, telemetria desativada |
| `OP_MODE_DEBUG` | 1 | Modo debug: FSM suspensa, apenas comandos assíncronos e telemetria |

A troca de modo é processada pela função `handleModeToggle()`, chamada no início de cada iteração do loop principal, com prioridade sobre as demais funções. Ao entrar no modo Debug, o motor é travado (`stepperStopEngaged()`), o flash é apagado via `flashPWM_Stop()` e um padrão de pisca no LED de debug confirma a transição. Ao retornar ao modo FSM, o estado é redefinido para `STATE_IDLE` e `last_state` para `STATE_NONE`, forçando a execução das entry actions.

O comando `SW_RESET_MSG (0x33)` provoca um reset por software via `NVIC_SystemReset()`, com um delay de 50 ms para garantir que o frame de confirmação seja transmitido antes do reset.

---

## 8. Máquina de Estados Finitos (FSM)

A FSM principal da aplicação é implementada na função `FSM()`, chamada no loop principal somente quando `operationMode == OP_MODE_FSM`. O padrão utilizado separa explicitamente as **entry actions** (executadas uma única vez na transição de estado) das **actions de estado** (executadas a cada iteração).

A condição de entrada é verificada por `state != last_state`. Ao executar a entry action, `last_state` é igualado a `state`, fechando a condição.

### 8.1 Descrição dos Estados

**`STATE_IDLE` (0):** Estado inicial e de repouso. O flash é desligado via `flashPWM_Stop()`, a cancela é fechada (`SetServoAngle(0)`) e o motor é habilitado em modo follow-steps. A cada iteração, é solicitado um movimento de 350 passos. A transição ocorre quando `SENS1_flag == 1` (objeto detectado na entrada da esteira), momento em que `objDetectedMSG_flag` é setada para notificar o Raspberry Pi.

**`STATE_OBJECT_DETECTED` (1):** O motor continua em movimento (350 passos por iteração). A transição ocorre quando `SENS2_flag == 1` (objeto sob a câmera), momento em que `classificationRequestMSG_flag` é setada, solicitando ao Raspberry Pi que realize a leitura do QR code e envie o destino.

**`STATE_WAIT_CLASSIFICATION` (2):** O flash é ligado com efeito fade via `flashPWM_Start()` e o motor é parado com o eixo travado (`stepperStopEngaged()`). A cada iteração, `flashPWM_Sweep()` atualiza o duty cycle do TIM17, produzindo o efeito visual de fade-in/fade-out contínuo. O firmware aguarda o recebimento de `ROUTE_A_RECEIVE_MSG (0xDA)` ou `ROUTE_B_RECEIVE_MSG (0xDB)`. Ao receber o destino, o frame é confirmado com `CMD_OK` e a flag de encaminhamento correspondente é setada.

**`STATE_ROUTE_A` (3):** A cancela é mantida fechada (`SetServoAngle(closeAngle)`), o flash é desligado via `flashPWM_Stop()` e o motor retoma o movimento. A transição ocorre quando `SENS3_flag == 1` (objeto saiu pela Rota A), setando `routeASuccesDeliveryMSG_flag` e retornando a `STATE_IDLE`.

**`STATE_ROUTE_B` (4):** A cancela é aberta (`SetServoAngle(openAngle)`), o flash é desligado via `flashPWM_Stop()` e o motor retoma o movimento. A transição ocorre quando `SENS4_flag == 1` (objeto saiu pela Rota B), setando `routeBSuccesDeliveryMSG_flag` e retornando a `STATE_IDLE`.

---

## 9. Procedimento de Inicialização e Handshake

Antes de entrar no loop principal, o firmware executa uma rotina de inicialização que bloqueia até que duas condições sejam satisfeitas:

1. **Todos os quatro sensores operacionais:** `SENS1_freq == 200 && SENS2_freq == 200 && SENS3_freq == 200 && SENS4_freq == 200`. Enquanto isso não ocorre, o LED de debug pisca rapidamente (100 ms).

2. **Handshake com o Raspberry Pi:** o STM32 aguarda receber `[0xAA][0x10]` (`SYS_RDY_MSG`). Após receber os sensores prontos + o handshake, responde com `[0x90][0x01]` (`SYS_INIT_MSG`) seguido de `[0x90][0x11]` (`MODE_FSM_MSG`), informando o modo de operação inicial. Enquanto aguarda o handshake com os sensores já prontos, o LED pisca lentamente (500 ms).

---

## 10. Controle Assíncrono (Modo Debug)

No modo Debug, a função `handleAsyncCommands()` processa os comandos recebidos para controle individual dos periféricos:

| Comando | Ação |
|---|---|
| `LIGHT_EN (0xE1)` | Inicia PWM do TIM17 com duty fixo `FLASH_SWEEP_MAX` (~95%) |
| `LIGHT_DISABLE (0xD1)`| `flashPWM_Stop()` — para PWM e força pino em LOW |
| `GATE_OPEN (0xE2)` | `SetServoAngle(openAngle)` |
| `GATE_CLOSE (0xD2)` | `SetServoAngle(closeAngle)` |
| `STPR_EN (0xE3)` | `stepperFollowSteps()` |
| `STPR_DISABLE (0xD3)` | `stepperStopDisengaged()` |
| `STPR_FORWARD (0xE4)` | Define `stepperDirInst = 0` |
| `STPR_BACKWARD (0xD4)`| Define `stepperDirInst = 1` |
| `STPR_TGT_STPS (0xE5)`| `targetStepps = rxDATA` |

Cada comando recebe uma confirmação `[0x90][CMD_eco]`. Comandos não reconhecidos retornam `[0x91]`.

---

## 11. Resumo das GPIOs

| Pino | Direção | Função |
|---|:---:|---|
| DIR  | Saída | Direção do motor de passo (A4988) |
| STEP | Saída | Pulsos de passo (A4988) |
| SLEEP| Saída | Enable/Sleep do driver A4988 |
| dbgLED | Saída | LED de diagnóstico |
| FLASH_PWM_Pin | Saída (TIM17 CH1) | PWM de brilho variável do flash de iluminação |

---

## 12. Alterações em Relação à Versão 3.0

| Aspecto | v3.0 | v3.1 |
|---|---|---|
| Controle do flash | GPIO direta (ON/OFF binário) | PWM via TIM17 com fade-in/fade-out |
| Timer utilizado pelo flash | — | TIM17 (prescaler = 63, ARR = 999, 1 kHz) |
| Entry action `STATE_WAIT_CLASSIFICATION` | Liga GPIO do flash | `flashPWM_Start()` — inicia sweep |
| Loop de `STATE_WAIT_CLASSIFICATION` | Apenas aguarda rota | `flashPWM_Sweep()` + aguarda rota |
| Entry actions `STATE_ROUTE_A/B/IDLE` | Desliga GPIO do flash | `flashPWM_Stop()` — para PWM e força LOW |
| Modo Debug — `LIGHT_EN` | `HAL_GPIO_WritePin(HIGH)` | `HAL_TIM_PWM_Start` + CCR = `FLASH_SWEEP_MAX` |
| Modo Debug — `LIGHT_DISABLE` | `HAL_GPIO_WritePin(LOW)` | `flashPWM_Stop()` |
| Transição para modo Debug | Desliga GPIO do flash | `flashPWM_Stop()` |

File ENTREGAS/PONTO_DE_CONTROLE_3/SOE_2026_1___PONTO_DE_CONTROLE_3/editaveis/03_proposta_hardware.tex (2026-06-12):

\begin{figure}[H]
    \centering
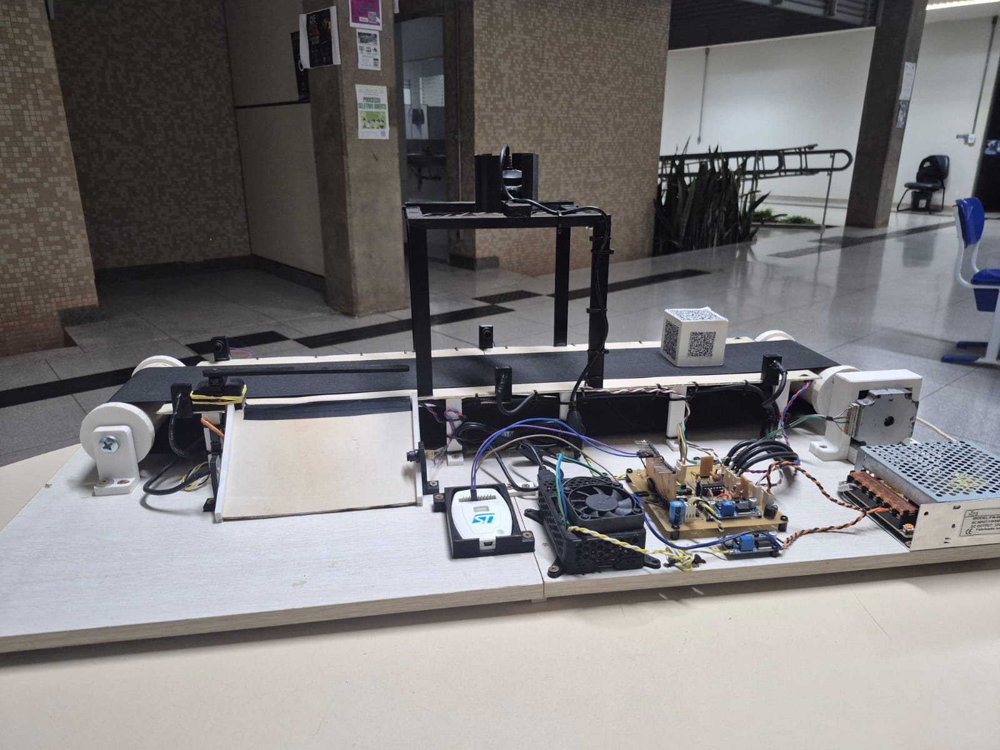
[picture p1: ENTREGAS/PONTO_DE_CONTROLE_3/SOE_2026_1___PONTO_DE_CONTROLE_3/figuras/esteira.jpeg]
    
    \caption{Foto da esteira}
    \label{fig:esteira}
\end{figure}\subsection{Descrição de \textit{hardware}}\label{subsec:hardware}

O sistema é composto por uma arquitetura híbrida que divide as responsabilidades entre um microprocessador Broadcom BCM2837, hospedado na placa Raspberry Pi 3B e responsável pelas tarefas de alto nível, e um microcontrolador STM32G070, dedicado ao controle em tempo real dos dispositivos físicos da esteira. O diagrama de blocos da Fig.~\ref{fig:Diag_blocks} ilustra de forma simplificada a arquitetura do sistema.

\begin{figure}[H]
    \centering
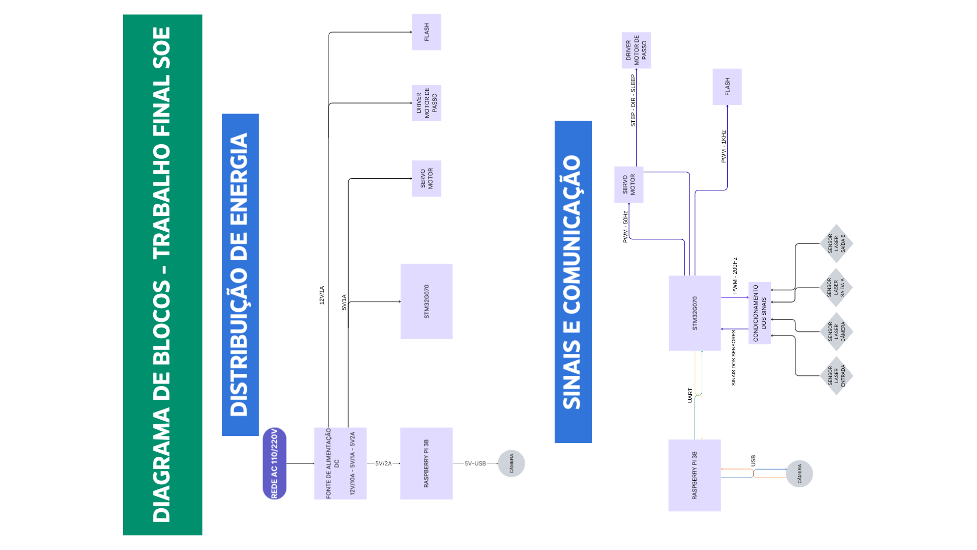
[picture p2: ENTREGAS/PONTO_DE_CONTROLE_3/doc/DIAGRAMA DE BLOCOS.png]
    
    \caption{Diagrama de blocos do \textit{hardware}.}
    \label{fig:Diag_blocks}
\end{figure}

\newpage
A placa Raspberry Pi 3B foi escolhida devido à ampla documentação disponível, à acessibilidade ao \textit{hardware}, uma vez que um dos integrantes da dupla já dispunha de uma unidade em funcionamento, e ao suporte nativo ao sistema operacional Linux, requisito para a execução da interface gráfica e dos algoritmos de visão computacional desenvolvidos neste projeto.

A câmera utilizada para a leitura e processamento de imagem é uma \textit{webcam} genérica da marca Multilaser, com interface USB. A escolha foi motivada pela ausência de necessidade de \textit{drivers} proprietários para o correto funcionamento com o Linux embarcado e pela disponibilidade imediata para o projeto.

O microcontrolador STM32G070 foi escolhido por sua variedade de periféricos adequados à aplicação, como comunicação UART, \textit{timers} de uso geral e recurso de DMA (\textit{Direct Memory Access}), que permite processar informações obtidas pelos periféricos sem ocupar a CPU. Além dessas características, o STM32G070 opera a uma frequência de CPU de 64\,MHz e é suportado pelo ambiente de desenvolvimento integrado STM32CubeIDE, da STMicroelectronics, referência mundial na fabricação e suporte de microcontroladores para a indústria. O esquemático de conexão do microcontrolador pode ser observado na Fig.~\ref{fig:sch_stm32}. Os \textit{timers} são utilizados da seguinte forma:

\begin{itemize}
    \item \textbf{TIM15:} gera o sinal PWM de frequência fixa (200\,Hz, \textit{duty cycle} de 50\,\%) utilizado para modular os lasers dos sensores;
    \item \textbf{TIM3:} configurado em modo \textit{Input Capture} com DMA, realiza a medição de frequência dos quatro sensores laser simultaneamente;
    \item \textbf{TIM16:} gera o sinal PWM de 50\,Hz com \textit{duty cycle} variável para o controle do servo motor;
    \item \textbf{TIM17:} gera o sinal PWM de 1K\,Hz com \textit{duty cycle} variável para o controle da luminária;
    \item \textbf{TIM6:} opera a 1\,MHz e dispara interrupções periódicas para o controle preciso dos pulsos enviados ao \textit{driver} do motor de passo.
\end{itemize}

\begin{figure}[H]
    \centering
    
    \caption{Esquemático do microcontrolador STM32G070.}
    \label{fig:sch_stm32}
\end{figure}

A interface de programação e depuração do STM32G070 é realizada via \textit{Serial Wire Debug} (SWD), conectada ao ST-Link V2 conforme o esquemático da Fig.~\ref{fig:sch_swd}. Os sinais SWCLK, SWDIO e NRST permitem gravar o \textit{firmware} e depurar o sistema em tempo real diretamente pelo STM32CubeIDE.

\begin{figure}[H]
    \centering
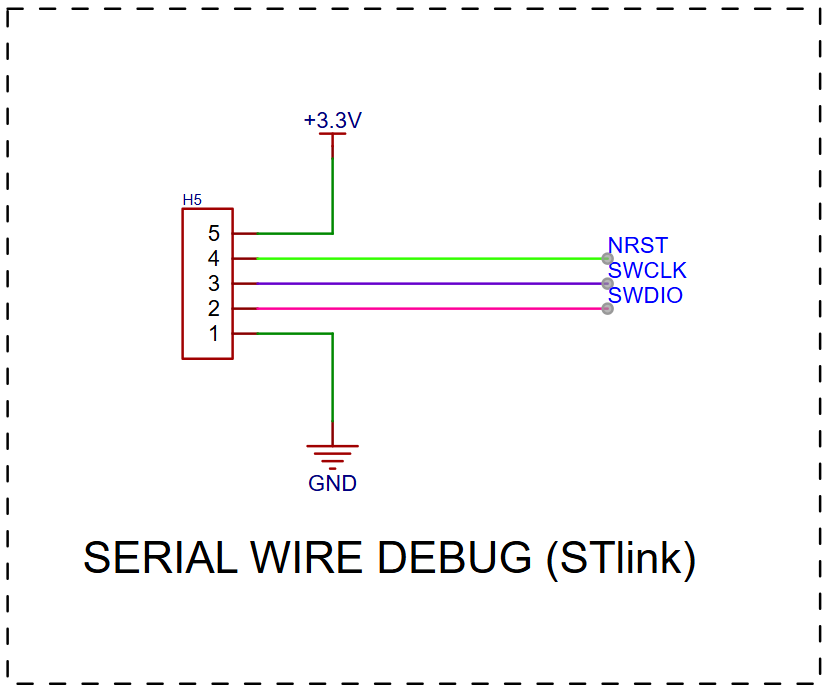
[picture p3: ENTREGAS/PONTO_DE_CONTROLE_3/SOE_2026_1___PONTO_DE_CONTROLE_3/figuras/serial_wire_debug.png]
    
    \caption{Esquemático da interface \textit{Serial Wire Debug} (ST-Link).}
    \label{fig:sch_swd}
\end{figure}

A comunicação serial entre o STM32G070 e o Raspberry Pi 3B é realizada via UART, convertida para USB por meio de um módulo conversor dedicado, cujo esquemático é apresentado na Fig.~\ref{fig:sch_uart_usb}. Esse conversor permite que o Raspberry Pi acesse a porta serial do microcontrolador como um dispositivo \texttt{/dev/ttyUSB}, sem necessidade de adaptação de nível lógico adicional, uma vez que tanto o STM32 quanto o conversor operam em 3,3\,V.

\begin{figure}[H]
    \centering
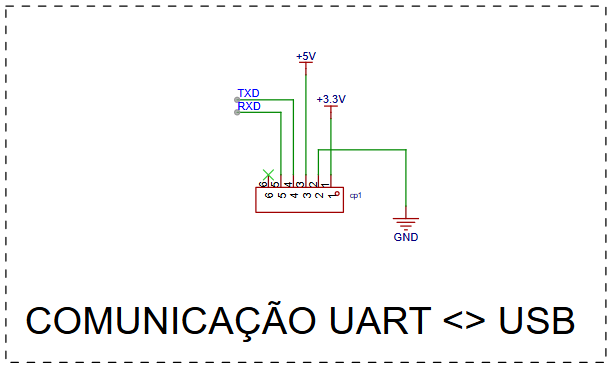
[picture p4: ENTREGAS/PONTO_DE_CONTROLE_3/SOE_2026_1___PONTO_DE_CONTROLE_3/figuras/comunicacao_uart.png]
    
    \caption{Esquemático do conversor UART $\leftrightarrow$ USB.}
    \label{fig:sch_uart_usb}
\end{figure}

A alimentação do sistema é gerenciada por dois estágios de regulação, conforme o esquemático da Fig.~\ref{fig:sch_alimentacao}. A tensão de entrada de 12\,V, proveniente de uma fonte externa, é convertida para 5\,V pelo módulo \textit{buck} LM2596S, protegido por um diodo 6A10 contra inversão de polaridade. O regulador linear AMS1117-3.3 deriva os 3,3\,V necessários para a alimentação do STM32G070 e dos circuitos de sinal a partir dos 5\,V. Capacitores de desacoplamento de 100\,nF estão presentes na entrada e saída do AMS1117-3.3 para rejeição de ruído de alta frequência.

\begin{figure}[H]
    \centering
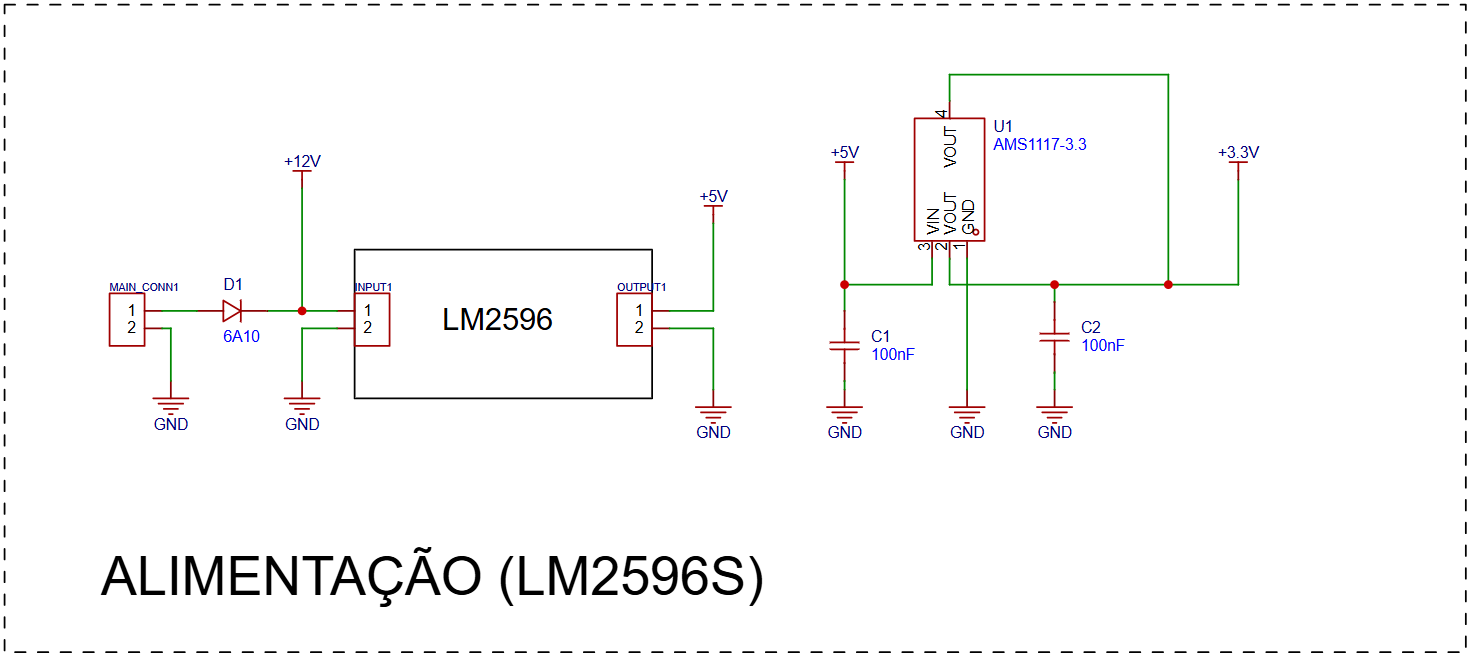
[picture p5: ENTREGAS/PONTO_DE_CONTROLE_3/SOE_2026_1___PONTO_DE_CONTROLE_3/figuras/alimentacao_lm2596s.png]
    
    \caption{Esquemático do circuito de alimentação (LM2596S + AMS1117-3.3).}
    \label{fig:sch_alimentacao}
\end{figure}

Como sistema motor do tapete da esteira, foi utilizado um motor de passo NEMA 22 controlado pelo \textit{driver} A4988, conforme o esquemático da Fig.~\ref{fig:sch_motor_passo}. Os pinos STEP, DIR e SLEEP são utilizados, respectivamente, para avançar um passo, definir a direção de rotação e habilitar ou desabilitar o \textit{driver} (liberando ou travando o eixo). Esses componentes foram escolhidos por sua disponibilidade e pela baixa complexidade operacional do \textit{driver}.

\begin{figure}[H]
    \centering
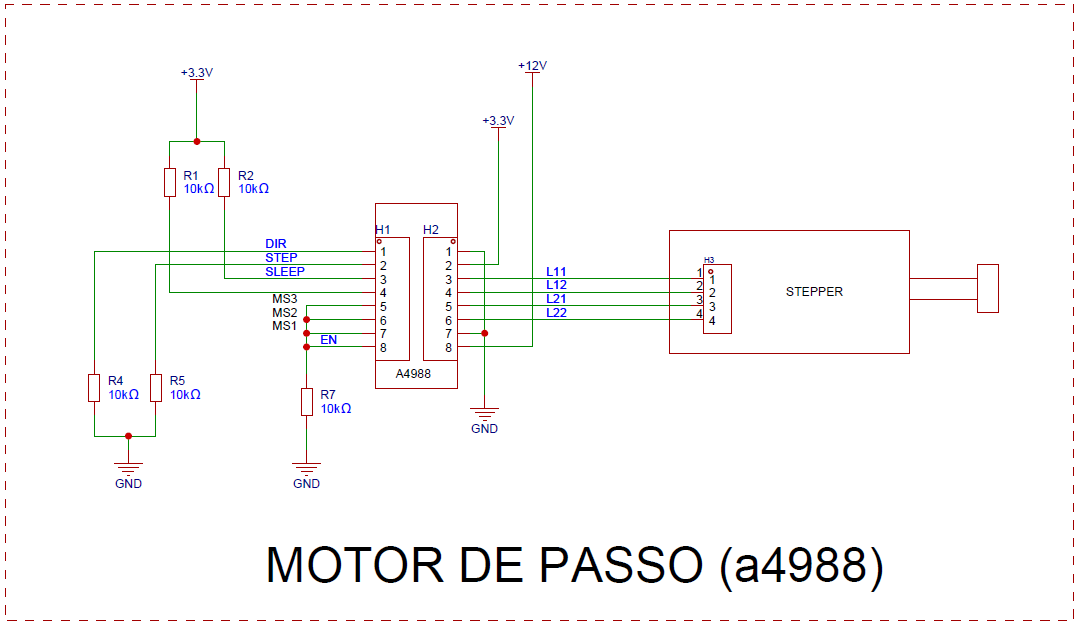
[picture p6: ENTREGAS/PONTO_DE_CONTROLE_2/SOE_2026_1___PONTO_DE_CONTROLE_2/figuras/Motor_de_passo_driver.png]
    
    \caption{Esquemático do motor de passo e do \textit{driver} A4988.}
    \label{fig:sch_motor_passo}
\end{figure}

Como atuador da cancela, foi utilizado o servo motor ES08MA (Fig.~\ref{fig:sch_servo_motor}), selecionado pela disponibilidade para o projeto e pelo torque superior ao do modelo SG90. O servo é controlado por PWM de 50\,Hz, com largura de pulso variando entre 600\,µs (0°) e 2300\,µs (180°), mapeada diretamente a partir do ângulo desejado pelo \textit{firmware}.

\begin{figure}[h]
    \centering
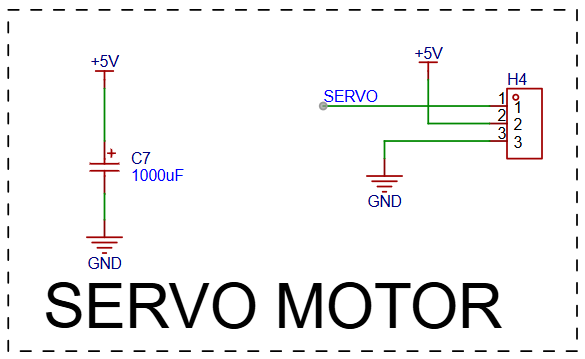
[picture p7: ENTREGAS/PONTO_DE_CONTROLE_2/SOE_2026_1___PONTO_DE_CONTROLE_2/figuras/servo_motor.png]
    
    \caption{Esquemático do servo motor ES08MA.}
    \label{fig:sch_servo_motor}
\end{figure}

Os sensores laser foram projetados para apresentar a maior simplicidade possível e para que o circuito eletrônico fosse viável de fabricação artesanal em \textit{breakout boards} com solda manual. O princípio de funcionamento é baseado em detecção síncrona por ausência de portadora: o laser modula seu feixe na frequência gerada pelo TIM15 (200\,Hz). O feixe incide sobre um LDR que, após condicionamento de sinal com amplificadores operacionais (LM324), entrega ao STM32G070 um sinal digital pulsado na faixa de 0 a 3,3\,V com frequência idêntica à portadora. Quando um objeto interrompe o feixe, a ausência do sinal pulsado, interpretada pelo \textit{firmware} como nível lógico alto permanente na entrada de captura, é identificada como presença de objeto à frente do sensor. O circuito conta com quatro instâncias desse sensor, dispostas em posições estratégicas ao longo da esteira: entrada da esteira (S1), zona de leitura do QR (S2), saída da Rota~A (S3) e saída da Rota~B (S4). O esquemático completo dos quatro sensores é apresentado na Fig.~\ref{fig:sch_sensores}.

\begin{figure}[H]
    \centering
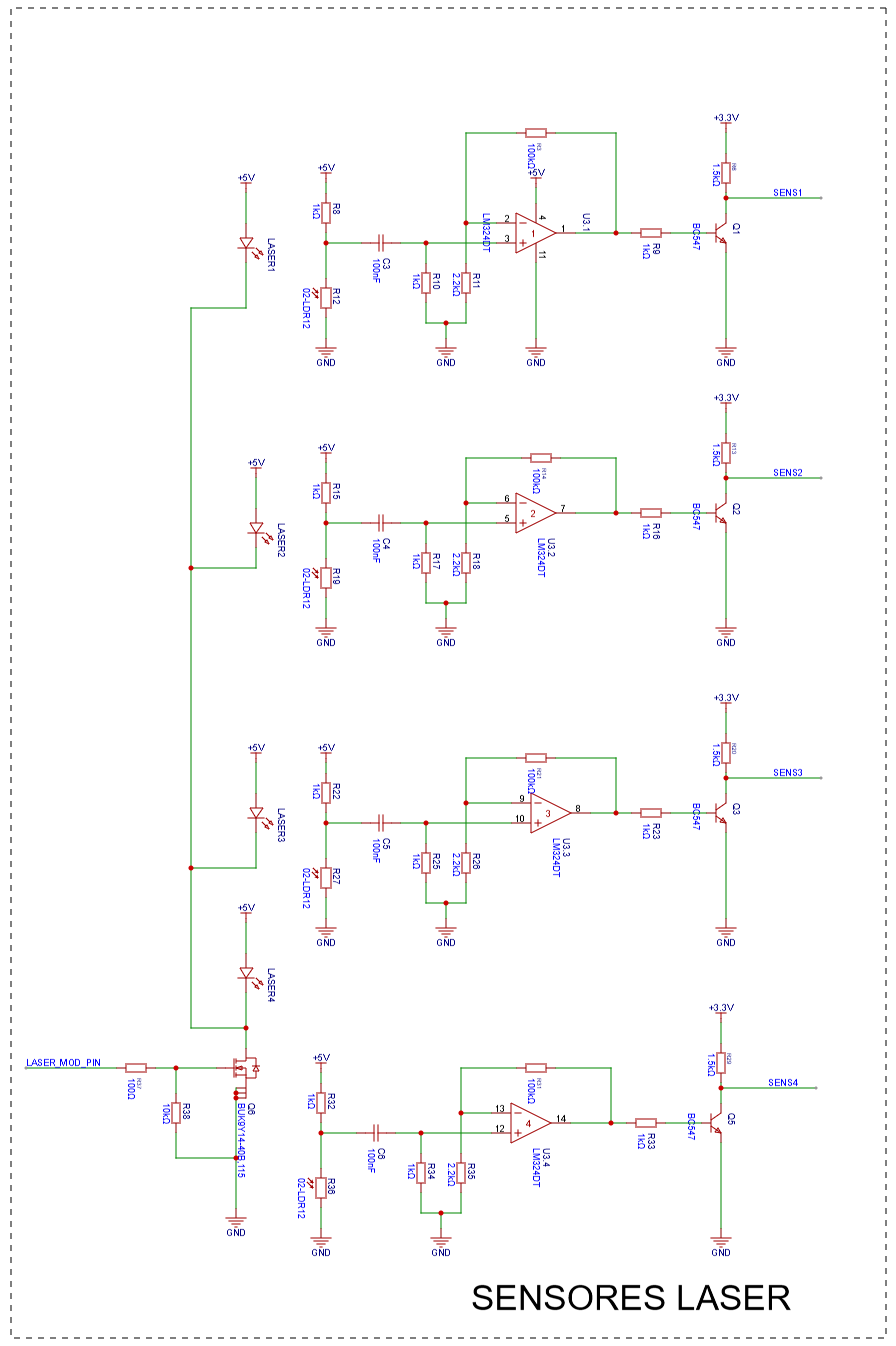
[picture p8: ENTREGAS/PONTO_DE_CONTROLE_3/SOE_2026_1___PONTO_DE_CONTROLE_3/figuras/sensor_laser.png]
    
    \caption{Esquemático dos quatro sensores laser com condicionamento de sinal (LDR + LM324).}
    \label{fig:sch_sensores}
\end{figure}

Para auxiliar a visualização do código QR pela câmera, o sistema conta com uma luminária composta por seis LEDs de uma fita LED 4000\,K. A temperatura de cor foi escolhida por apresentar maior similaridade com a luz ambiente, o que resultou em melhor qualidade de captura da câmera em comparação com fitas de 6500\,K. O acionamento da luminária é realizado por PWM controlado pelo canal 1 do TIM17 do STM32G070, por meio de um MOSFET BUK9Y14 em configuração de chave, como ilustrado no esquemático da Fig.~\ref{fig:sch_luminaria}.

\begin{figure}[H]
    \centering
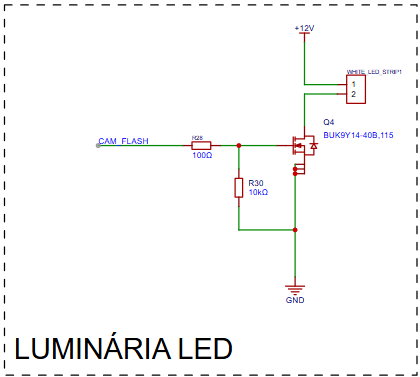
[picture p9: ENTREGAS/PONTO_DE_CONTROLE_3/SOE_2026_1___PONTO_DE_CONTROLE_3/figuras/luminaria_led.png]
    
    \caption{Esquemático do circuito de acionamento da luminária LED.}
    \label{fig:sch_luminaria}
\end{figure}

O esquemático completo da placa de circuito montada para o projeto encontra-se disponível no repositório do projeto~\cite{ref:github_soe}.

Para a montagem completa do sistema, foi elaborada a lista de materiais apresentada nas Tabelas~\ref{tab:BOM_eletro} e~\ref{tab:BOM_mec}, mais informações, incluindo os arquivos geratriz e .STL das peças podem ser encontrados no GitHub ~\cite{ref:github_soe}.
 
% === ELETRÔNICA ================================================
\begin{table}[H]
\caption{Lista de materiais --- Eletrônica.}
\label{tab:BOM_eletro}
\centering
\renewcommand{\arraystretch}{0.85}
\small
\begin{tabular}{lcc}
\hline
\textbf{Componente} & \textbf{Preço unit. (R\$)} & \textbf{Qtd.} \\
\hline
Raspberry Pi 3B                        & ---   & 1  \\
\textit{Webcam} genérica               & ---   & 1  \\
ST-Link V2                             & ---   & 1  \\
STM32G070                              & 5,50  & 1  \\
\textit{Driver} A4988                  & 18,00 & 1  \\
AMS1117-3.3                            & 1,00  & 1  \\
Módulo \textit{Buck} LM2596S           & 15,00 & 1  \\
AmpOp LM324                            & 3,50  & 1  \\
Diodo 1N4007                           & 0,50  & 1  \\
Capacitor eletrolítico 1000\,$\mu$F    & 0,50  & 1  \\
Motor de passo NEMA 22                 & 60,00 & 1  \\
Servo motor ES08MA                     & 25,00 & 1  \\
MOSFET BUK9Y14                         & 1,00  & 2  \\
Transistor BJT BC547B                  & 0,20  & 4  \\
Resistor 100\,$\Omega$                 & 0,10  & 3  \\
Resistor 1\,k$\Omega$                  & 0,10  & 12 \\
Resistor 1k5\,$\Omega$                 & 0,10  & 4  \\
Resistor 2k2\,$\Omega$                 & 0,10  & 4  \\
Resistor 10\,k$\Omega$                 & 0,10  & 8  \\
Resistor 100\,k$\Omega$                & 0,10  & 4  \\
LDR 10\,k$\Omega$                      & 0,50  & 4  \\
Laser com ajuste focal                 & 1,00  & 4  \\
Capacitor 100\,nF                      & 0,10  & 6  \\
Fio coaxial (sensores LDR)             & 10,00 & 2\,m \\
Fio 22\,AWG vermelho (lasers)          & 1,50  & 2\,m \\
Fio 22\,AWG azul (lasers)              & 1,50  & 2\,m \\
Fio 22\,AWG preto (servo)              & 1,50  & 1\,m \\
Fio 22\,AWG branco (servo)             & 1,50  & 1\,m \\
Fio 22\,AWG amarelo (servo)            & 1,50  & 1\,m \\
Conector Molex KK macho 2 terminais    & 0,10  & 8  \\
Conector Molex KK macho 3 terminais    & 0,15  & 2  \\
Conector Molex KK fêmea 2 terminais    & 0,10  & 8  \\
Conector Molex KK fêmea 3 terminais    & 0,15  & 2  \\
\hline
\textbf{Total (itens com preço definido)} & \textbf{163,80} & \\
\hline
\end{tabular}
\end{table}
 
% === MECÂNICA ==================================================
\begin{table}[H]
\caption{Lista de materiais --- Mecânica.}
\label{tab:BOM_mec}
\centering
\renewcommand{\arraystretch}{0.85}
\small
\begin{tabular}{lcc}
\hline
\textbf{Componente} & \textbf{Preço unit. (R\$)} & \textbf{Qtd.} \\
\hline
Perfil de alumínio 20$\times$20\,mm    & ---   & ---  \\
Chapa de PVC (rampa saída B)           & ---   & 1    \\
Tapete de PVC                          & ---   & 1    \\
Rolo motriz (impressão 3D)             & ---   & 1    \\
Rolo bobo (impressão 3D)               & ---   & 1    \\
Lateral esq. mesa esteira (imp. 3D)    & ---   & 1    \\
Lateral dir. mesa esteira (imp. 3D)    & ---   & 1    \\
Lateral esq. rampa (imp. 3D)           & ---   & 1    \\
Lateral dir. rampa (imp. 3D)           & ---   & 1    \\
Cancela servo (imp. 3D)                & ---   & 1    \\
Suporte servo (imp. 3D)                & ---   & 1    \\
Suporte ST-Link (imp. 3D)              & ---   & 1    \\
Suporte laser c/ ajuste focal (imp. 3D)& ---   & 3    \\
Suporte LDR (imp. 3D)                  & ---   & 3    \\
Suporte laser rampa (imp. 3D)          & ---   & 1    \\
Suporte LDR rampa (imp. 3D)            & ---   & 1    \\
Suporte \textit{flash} esteira (imp. 3D)& ---  & 2    \\
Suporte poste câmera (imp. 3D)         & ---   & 2    \\
Suporte câmera esteira (imp. 3D)       & ---   & 1    \\
\hline
\end{tabular}
\end{table}

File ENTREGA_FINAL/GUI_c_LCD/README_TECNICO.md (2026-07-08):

# Esteira Separadora — Descrição Técnica dos Algoritmos

---

## Visão Geral da Arquitetura

```
Raspberry Pi 3B
└─ main.c
   ├─ serial_open()  ────────────►  UART 8N1 115200  ◄────────────►  STM32G070
   └─ select_mode()
      ├─ fsm_run()
      │  ├─ Thread RX (pthread)  ◄── protocol_parse_byte()
      │  └─ camera_read_qr()     ◄── OpenCV (C++) + ZBar
      ├─ debug_run()
      │  └─ Thread RX (pthread)  ◄── protocol_parse_byte()
      └─ hmi_run()
         ├─ camera_init()
         ├─ do_handshake()
         └─ hmi_operate()
            ├─ Thread RX (pthread)  ◄── protocol_parse_byte()
            ├─ camera_read_qr()     ◄── OpenCV (C++) + ZBar
            ├─ lcd2004_i2c.c        ──► /dev/i2c-X (display LCD)
            ├─ gpio_button.c        ──► GPIO START / STOP
            └─ gpio_buzzer.c        ──► GPIO buzzer (alerta)
```

`fsm_run()` e `debug_run()` executam o handshake (`do_handshake()`)
antes de entrar no loop, feito por `main.c`. `hmi_run()` adia o
handshake até o operador pressionar START na tela de espera.

---

## Protocolo de Comunicação (proprietário, binário, UART 8N1)

### Características

| Parâmetro | Valor |
|---|---|
| Camada física | UART 115200 bps, 8 bits, sem paridade, 1 stop bit |
| Sincronização | Byte de status fixo como delimitador de início |
| Tamanho de frame | 1, 2 ou 3 bytes (fixo por comando) |
| CRC / checksum | **Nenhum** |
| Campo de comprimento | **Nenhum** |
| Endereçamento | Ponto a ponto (sem múltiplos nós) |
| ACK implícito | Echo do comando pelo STM32 |

### Estrutura dos Frames

**TX — Raspberry Pi → STM32**

```
Frame padrão (2 bytes):
┌────────┬────────┐
│  0xAA  │  CMD   │
└────────┴────────┘

Frame com dado (3 bytes) — somente SET_STPR_TGT_STPS:
┌────────┬────────┬────────┐
│  0xAA  │  0xE5  │  DATA  │
└────────┴────────┴────────┘
  DATA = número de passos (1–255)
```

**RX — STM32 → Raspberry Pi**

```
Erro (1 byte):
┌────────┐
│  0x91  │   CMD_ERR
└────────┘

Evento / confirmação (2 bytes):
┌────────┬────────┐
│  0x90  │  CMD   │   CMD_OK + payload
└────────┴────────┘

Telemetria de sensores (3 bytes):
┌────────┬────────┬────────┐
│  0x90  │  0x55  │ FLAGS  │
└────────┴────────┴────────┘
  FLAGS: bits 0-3 = sensores S1-S4 (1=objeto presente, 0=livre)
```

### Tabela de Comandos

| Direção | Byte | Nome | Significado |
|---|---|---|---|
| TX | `0x10` | `SYS_RDY` | Handshake — RPi pronto |
| RX | `0x01` | `SYS_INIT` | STM32 inicializado |
| RX | `0xA0` | `OBJ_DETECTED` | Sensor detectou objeto |
| RX | `0xC0` | `CLSS_REQUEST` | Objeto sob câmera, classifique |
| TX | `0xDA` | `ROUTE_A_SEND` | Enviar para Rota A |
| TX | `0xDB` | `ROUTE_B_SEND` | Enviar para Rota B |
| RX | `0xFA` | `ROUTE_A_FWD` | STM32 encaminhou para A |
| RX | `0xFB` | `ROUTE_B_FWD` | STM32 encaminhou para B |
| RX | `0xBA` | `ROUTE_A_OK` | Entrega em A confirmada |
| RX | `0xBB` | `ROUTE_B_OK` | Entrega em B confirmada |
| TX | `0xE1` | `LIGHT_EN` | Flash ligado |
| TX | `0xD1` | `LIGHT_DIS` | Flash desligado |
| TX | `0xE2` | `GATE_OPEN` | Cancela abrir |
| TX | `0xD2` | `GATE_CLOSE` | Cancela fechar |
| TX | `0xE3` | `STPR_EN` | Motor passo engajar |
| TX | `0xD3` | `STPR_DIS` | Motor passo livre |
| TX | `0xE4` | `STPR_FORWARD` | Motor passo — frente |
| TX | `0xD4` | `STPR_BACKWARD` | Motor passo — trás |
| TX | `0xE5` + N | `SET_STPR_TGT_STPS` | Motor passo — N passos |
| TX | `0xDD` | `DEBUG_TOGGLE` | Alterna modo DEBUG/FSM |
| TX/RX | `0x33` | `SW_RESET_MSG` | Reset por software |
| RX | `0x55` + FLAGS | `SENS_STATUS_MSG` | Telemetria sensores |

---

## Módulos

### `serial.c` — Camada Física

Abre `/dev/ttyS0` com `O_RDWR | O_NOCTTY | O_NONBLOCK` e configura
via `termios` para modo raw 8N1. A leitura com timeout usa `select()`
sobre o file descriptor — não bloqueia threads concorrentes.

Funções principais:

| Função | Comportamento |
|---|---|
| `serial_open()` | Abre, configura termios, faz flush do buffer RX |
| `serial_write()` | Escrita completa em loop (`EINTR`-safe) |
| `serial_read_byte_timeout()` | Lê 1 byte com timeout via `select()` |
| `serial_flush()` | `tcflush(TCIFLUSH)` — descarta bytes pendentes no RX |

---

### `protocol.c` — Parser de Frames

Implementa uma **máquina de estados de 3 fases** alimentada byte a byte.
O parser é stateful (variáveis estáticas internas), portanto não é
reentrante — deve ser chamado de uma única thread.

```
      byte 0x90 ou 0x91
WAIT_STATUS ──────────────────► WAIT_CMD
    │                               │
    │ outro byte → descartado       │ byte == 0x55
    │ (log_print ERR)               ▼
    │                           WAIT_DATA ──► frame completo (3 bytes)
    │                               │
    │                          outro byte
    │                               ▼
    └───────────────────────── frame completo (2 bytes)

    0x91 em WAIT_STATUS → frame de 1 byte (CMD_ERR) entregue imediatamente
```

Bytes que chegam no estado `WAIT_STATUS` e não são `0x90` nem `0x91`
são descartados com log de erro — indica ruído na linha ou
desalinhamento de frame.

---

### `fsm.c` — Máquina de Estados (Modo Autônomo)

#### Diagrama de Estados

```
         ┌──────────────────────────────────────────────────┐
         │                                                  │
         ▼                                                  │
      [IDLE] ──── OBJ_DETECTED ────► [OBJ_DETECTED]         │
         ▲                                │                 │
         │                         CLSS_REQUEST             │
         │                                │                 │
         │                                ▼                 │
         │                         [CLASSIFYING]            │
         │                        /            \            │
         │               CAM_ROUTE_A      CAM_ROUTE_B       │
         │                    │                 │           │
         │              ROUTE_A_SEND      ROUTE_B_SEND      │
         │                    │                 │           │
         │                    ▼                 ▼           │
         │               [ROUTE_A]         [ROUTE_B]        │
         │                    │                 │           │
         │              ROUTE_A_OK        ROUTE_B_OK        │
         │                    │                 │           │
         │             [DELIVERED_A]    [DELIVERED_B]       │
         │                    │                 │           │
         └────────────────────┴─────────────────┘           │
                         (sleep 2s)                         │
                                                            │
         Qualquer estado: SW_RESET_MSG ─────────────────────┘
```

#### Arquitetura de Threads

A thread RX é criada **antes** da inicialização da câmera. Isso é
intencional — o OpenCV leva ~2 s para abrir o dispositivo de vídeo,
e durante esse tempo o STM32 pode enviar eventos (ex: `OBJ_DETECTED`,
`CLSS_REQUEST`) que seriam perdidos se a thread ainda não estivesse
ativa. Com essa ordem, todos os eventos são capturados em
`ctx.rx_event` e processados pelo loop principal após a câmera estar
pronta.

```
main thread (fsm_run)          rx_thread
      │                             │
      │  pthread_create() ─────────►│  (sobe ANTES da camera)
      │                             │ serial_read_byte_timeout(100 ms)
      │  camera_init()              │ protocol_parse_byte()
      │  (~2s abertura OpenCV)      │ mutex_lock → ctx.rx_event = cmd
      │                             │ mutex_unlock
      │                             │
      │ fsm_consume_event()         │
      │  mutex_lock                 │
      │  ev = ctx.rx_event          │
      │  ctx.rx_event = 0           │
      │  mutex_unlock               │
      │                             │
      │ switch(state) + usleep(10ms)│
      │                             │
      │  ctx.running = 0 ──────────►│ (sai do loop)
      │  pthread_join() ◄───────────┘
```

A leitura da câmera (`camera_read_qr`) ocorre **na main thread**, de
forma síncrona, enquanto a thread RX continua recebendo bytes em paralelo.
Eventos que chegam durante a classificação são enfileirados em
`ctx.rx_event` e processados após o retorno da câmera.

---

### `camera.cpp` — Captura e Leitura de QR

Implementado em **C++** usando a API moderna do OpenCV (`cv::VideoCapture`,
`cv::Mat`) por exigência do OpenCV 4.x, que removeu suporte à API legada C.
As funções exportadas (`camera_init`, `camera_release`, `camera_read_qr`)
são declaradas com `extern "C"` para compatibilidade com os módulos C do
projeto. O ZBar recebe frames em escala de cinza (`Y800`).

#### Fluxo de captura

```
s_capture >> frame  (cv::VideoCapture)
    │
    ▼
cv::cvtColor(BGR → GRAY)
    │
    ▼
zbar_scan_image()
    │
    ├── n == 0 → nenhum QR → próximo frame
    │
    └── n > 0  → zbar_symbol_get_data()
                     │
                     ▼
               parse_qr_text()
                     │
                     ├── campo "Destino: 0xAADA" → extrai byte baixo
                     ├── campo "Destino: 0xDA"   → usa diretamente
                     └── varredura de tokens 0xXX no texto inteiro
```

#### Formato esperado do QR

```
Nome da Peca: <texto livre>
Destino: 0xAADA
```

`0xDA` → `ROUTE_A_SEND` (Rota A)
`0xDB` → `ROUTE_B_SEND` (Rota B)

O parser tenta duas estratégias em sequência: campo `Destino:` primeiro,
depois varredura linear do texto. Isso garante compatibilidade com QRs
que contenham apenas o token hexadecimal sem label.

---

### `debug.c` — Modo Interativo

Usa `select()` sobre `STDIN_FILENO` com timeout de 200 ms para ler
input do teclado sem bloquear a thread RX. A thread RX exibe
telemetria (`SENS_STATUS_MSG`) em tempo real enquanto o operador
digita comandos.

---

### `hmi.c` — Modo Display + Botões + Buzzer

Terceiro modo de operação, com mini-FSM própria (`HmiOpState`,
independente da `PcFsmState` de `fsm.c`) espelhando os mesmos eventos
de protocolo do Modo FSM, com saída em LCD 20x4 em vez de log no
terminal, e contadores de objetos entregues em cada rota.

```
[hmi_run() — tela de espera]
        │  button_was_pressed(btn_start)
        ▼
   camera_init(cam_index)
        │  sucesso
        ▼
   do_handshake(fd)
        │  sucesso
        ▼
[hmi_operate()]  ── mesma máquina de estados de fsm_run(), porém:
        │            • checa button_was_pressed(btn_stop) a cada
        │              iteração do loop (não só Ctrl+C)
        │            • checa button_was_pressed(btn_start) a cada
        │              iteração para zerar os contadores em operação
        │            • hmi_display_state() em vez de log_fsm_state()
        │            • falha em camera_read_qr() aciona o alerta de
        │              QR não identificado (ver abaixo)
        │
        ├─ STOP pressionado          ──► deinit_stm32(fd) ──► [tela de espera]
        └─ g_interrupted             ──► exibe mensagem final, encerra o modo
```

#### Alerta de QR não identificado e recuperação do handshake

Quando `camera_read_qr()` retorna `CAM_TIMEOUT` ou `CAM_ERROR`,
`hmi_operate()` entra em um fluxo de dois estágios antes de voltar à
operação normal:

```
camera_read_qr() → CAM_TIMEOUT / CAM_ERROR
        │
        ▼
hmi_wait_for_operator_ack()
  "QR nao identificado" / "Libere a esteira!" / "START p/ reiniciar"
  backlight + buzzer piscando a cada HMI_ALERT_BLINK_MS, sem timeout
        │
        ├─ STOP  ──────────────────────────► encerra a operação
        ├─ Ctrl+C ─────────────────────────► encerra a operação
        └─ START (HMI_ALERT_ACK)
                │
                ▼
        Pausa a thread RX (ctx.running = 0; pthread_join())
                │
                ▼
        deinit_stm32(fd)  +  handshake_send_ready(fd)
                │
                ▼
        Loop de handshake_poll(fd), sem timeout fixo, com
        backlight + buzzer piscando a cada HMI_ALERT_BLINK_MS
                │
                ├─ STOP / Ctrl+C          ──► encerra a operação
                ├─ handshake_poll() = -1  ──► CMD_ERR: volta à tela de espera
                └─ handshake_poll() = 1   ──► SYS_INIT: religa a thread RX,
                                              retoma hmi_operate() em
                                              HMI_OP_IDLE, contadores intactos
```

O reset e o reenvio do handshake não usam timeout fixo porque o
firmware do STM32 só emite `SYS_INIT` de forma espontânea quando os
sensores da esteira ficam livres (estado que o Raspberry Pi não
observa por nenhum outro canal). `handshake_send_ready()` envia
`SYS_RDY` uma única vez; `handshake_poll(fd)` é chamada repetidamente
(cada chamada bloqueia até ~100 ms em `serial_read_byte_timeout()`) até
receber `SYS_INIT` (retorno 1), `CMD_ERR` (retorno -1) ou nada (retorno
0). A thread RX de `hmi_operate()` é pausada durante todo esse processo
porque `handshake_send_ready()`/`deinit_stm32()` acessam a UART
diretamente e usam o parser estático de `protocol.c`, que não é
reentrante.

#### Contadores de objetos entregues

`s_count_a` e `s_count_b` (variáveis estáticas em `hmi.c`) são
incrementados ao receber `ROUTE_A_OK`/`ROUTE_B_OK` e exibidos em toda
tela do modo HMI via `hmi_format_counts()`. Persistem entre ciclos de
operação (START na tela de espera não os afeta) e só são zerados por
`hmi_reset_counts()`, chamada quando `button_was_pressed(btn_start)`
é detectado dentro do loop de `hmi_operate()` (ou seja, com a operação
já em andamento).

#### Dependências de hardware, isoladas em módulos próprios

- `lcd2004_i2c.c` — driver HD44780 4-bit via backpack I2C PCF8574
  (`/dev/i2c-X` + `ioctl(I2C_SLAVE)`). Mapeamento de pinos do
  backpack: `P0=RS P1=RW P2=E P3=Backlight P4-P7=D4-D7`. O
  endereçamento de DDRAM das 4 linhas do 2004A não é contíguo
  (linhas 0/2 começam em `0x00`/`0x14`, linhas 1/3 em `0x40`/`0x54`)
  -- peculiaridade conhecida do HD44780 em displays 20x4.
  `lcd_print_line()` sobrescreve a linha inteira com padding de
  espaços para evitar flicker (sem `lcd_clear()` a cada atualização
  de estado). `lcd_set_backlight()` escreve apenas o bit de
  backlight no PCF8574 com `E` em nível baixo, portanto não afeta o
  conteúdo exibido nem a posição do cursor. O controlador não
  entende UTF-8: strings devem ser ASCII puro, sem acentuação.

- `gpio_button.c` — leitura por polling via libgpiod (API v1:
  `gpiod_chip_open_by_name` / `gpiod_line_request_input_flags` /
  `gpiod_line_get_value`), sem bias interno (pull-up é externo ao
  circuito do botão, nível 0 = pressionado). Debounce por
  software configurável (`HMI_BTN_DEBOUNCE_MS` em `hmi.h`): uma
  borda de descida só é reportada como press válido se o nível
  baixo persistir pelo tempo configurado desde a primeira
  amostra; cada press é entregue uma única vez por pressão
  (consumido até o botão ser solto e pressionado novamente).

- `gpio_buzzer.c` — saída digital simples via libgpiod (API v1:
  `gpiod_line_request_output`), nível 1 = ligado. `buzzer_set()`
  e `buzzer_close()` aceitam ponteiro `NULL`, permitindo que o
  modo HMI funcione normalmente (alertas apenas com o backlight
  piscando) quando o buzzer não está conectado.

---

### `log.c` — Sistema de Log

Todas as mensagens imprimem `HH:MM:SS.mmm` via `clock_gettime(CLOCK_REALTIME)`
seguido de prefixo ANSI colorido e texto formatado (`vprintf`).
O `fflush(stdout)` ao final garante saída imediata mesmo com redirecionamento.

A função `log_fsm_state()` imprime adicionalmente um **pipeline visual**
da FSM em linha, indicando o estado ativo com destaque bold:

```
          [IDLE]  >  OBJ  >  CLASS  >  ROTA A  >  ROTA B
```

---

## Sequência de Inicialização (Handshake)

```
RPi                            STM32
 │                               │
 │── [0xAA][0x10]  SYS_RDY ────► │
 │                               │
 │◄─ [0x90][0x01]  SYS_INIT ──── │  (dentro de 10 s)
 │                               │
 │   Handshake OK                │
 │                               │
 │── [0xAA][0xDA ou 0xDB] ──────►│  (após classificação)
```

`do_handshake()` (usada nos modos FSM, DEBUG e no handshake inicial do
modo HMI, disparado ao pressionar START na tela de espera) envia
`SYS_RDY` e aguarda `SYS_INIT` por até `HANDSHAKE_TIMEOUT_MS`
(10 000 ms); se o tempo esgotar, retorna erro e o chamador decide como
tratar a falha. Durante a espera, o log emite heartbeats a cada ~2 s.

`handshake_send_ready()` + `handshake_poll()` (usadas em `hmi.c` na
recuperação após o alerta de QR não identificado) separam o envio do
`SYS_RDY` da espera pela resposta, sem timeout fixo: o chamador chama
`handshake_poll()` em loop até obter `SYS_INIT` (1), `CMD_ERR` (-1) ou
nenhuma resposta ainda (0). Essa variante existe porque, nesse ponto
específico do modo HMI, a resposta do STM32 só é enviada quando os
sensores da esteira ficam livres, o que pode levar mais tempo do que
o timeout fixo de `do_handshake()` permitiria.

---

## Dependências e Versões

| Biblioteca | Pacote apt | Uso |
|---|---|---|
| OpenCV 4.x | `libopencv-dev` | Captura de câmera (API C++ moderna) |
| ZBar | `libzbar-dev` | Decodificação de QR / barcode |
| libgpiod | `libgpiod-dev` | Polling dos botões START/STOP e saída digital do buzzer (API v1) |
| pthreads | glibc (nativo) | Thread RX em background |
| termios | glibc (nativo) | Configuração da UART |
| ioctl I2C (`linux/i2c-dev.h`) | glibc/kernel headers (nativo) | Comunicação com o backpack PCF8574 do LCD |

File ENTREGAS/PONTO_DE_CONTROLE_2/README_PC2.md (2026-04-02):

# README_PC2 — Funcionamento Básico

## Objetivo
Validar o funcionamento individual das partes fundamentais do sistema utilizando o Raspberry Pi.

## Entregáveis

### Implementação
- Conectar os módulos principais ao Raspberry Pi  
- Testar cada componente individualmente  

Exemplos de módulos:
- Sensores (temperatura, presença, etc.)  
- GPS  
- Câmera  
- Comunicação (e-mail, rede, etc.)  

### Demonstração
- Comprovação de que cada módulo funciona corretamente  
- Testes individuais documentados  

### Tecnologias Permitidas
- Linguagens interpretadas (Python, Octave, etc.)  
- Bibliotecas prontas  

### Documento (Relatório Parcial)
O relatório deve conter:

- Descrição do hardware utilizado  
- Descrição do software desenvolvido  
- Resultados obtidos nos testes  

## Critérios de Avaliação
- Funcionamento correto dos módulos  
- Clareza na descrição técnica  
- Organização dos testes  
- Coerência entre hardware e software  

## Observações
- Não é necessário integração completa ainda  
- Foco na validação individual dos componentes

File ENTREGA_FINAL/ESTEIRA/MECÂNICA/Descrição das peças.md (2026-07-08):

# Descrição das Peças Mecânicas — Esteira Separadora SOE

---

## Peças do Subsistema Estrutural
*Autor: Paulo Caleb Fernandes da Silva*

---

### `Wood_stitches_Esteira_Rolante_SOE.catPART`
**Quantidade:** 3 unidades

Peças plásticas retangulares com dois furos espaçados para fixar duas partes de madeira que compõem a base da esteira. Funcionam como "pontos" que seguram uma madeira na outra e conferem rigidez à base.

---

### `Apoio_Base_Esteira_Rolante_SOE.catPART`
**Quantidade:** 8 unidades

Bases de apoio retangulares com quatro furos para parafusos e um ressalto para servir de pé para a esteira. São utilizadas para duas funções simultaneamente: complementam a costura das peças de madeira e servem de espaçadores da base em relação ao solo.

---

### `Suporte_Motor_Esteira_Rolante_SOE.catPART`
**Quantidade:** 1 unidade

Base de fixação do motor de passo para garantir estabilidade mecânica do motor NEMA 22 e alinhá-lo com o suporte do rolo.

---

### `Trava_Suporte_Motor_Esteira_Rolante_SOE.catPART`
**Quantidade:** 1 unidade

Aro de fixação do motor de passo da esteira. É responsável por auxiliar a fixação do motor em conjunto com o `Suporte_Motor_Esteira_Rolante_SOE`. As duas peças trabalham juntas para manter a fixação do motor de passo.

---

### `Suporte_Parafuso_Esteira_Rolante_SOE.catPART`
**Quantidade:** 3 unidades

Suporte do parafuso que faz o alinhamento do rolo da esteira. O parafuso é fixado ao suporte e cria um ponto de eixo para o rolamento do rolo. É utilizado tanto para o rolo motriz (associado ao motor de passo) quanto para o rolo bobo (utilizando dois suportes para criar os dois pontos de eixo do rolo).

---

### `Tampa_Rolo_Motor_Esteira_Rolante_SOE.catPART`
**Quantidade:** 1 unidade

Tampa do rolo motriz, que associa o eixo do motor de passo à estrutura do rolo. Em conjunto com a `Tampa_Rolo_Rolamento_Esteira_Rolante_SOE` e um cano de PVC de 50 mm, forma o rolo motriz da esteira.

---

### `Tampa_Rolo_Rolamento_esteira_rolante_SOE.catPART`
**Quantidade:** 3 unidades

Tampa do rolo bobo, que associa o eixo do parafuso à estrutura do rolo. O rolo motriz utiliza uma unidade desta peça, enquanto o rolo bobo utiliza duas. A fixação do rolo bobo emprega dois `Suporte_Parafuso_Esteira_Rolante_SOE` em conjunto com dois rolamentos 608 que se apoiam nos parafusos fixados aos suportes.

---

### `Suporte_mesa_Rolante_SOE.catPART`
**Quantidade:** 6 unidades

Suporte para a chapa de PVC que forma a mesa da esteira. Um conjunto dessas peças forma a base da mesa por onde corre o tapete, guiado pelo motor de passo a partir do rolo motriz e do rolo bobo.

---

### `Lateral_esq_rampa_esteira_rolante_SOE.catPART`
**Quantidade:** 1 unidade

Lateral esquerda com alojamento para encaixe de uma chapa de PVC que forma a rampa da saída B da esteira.

---

### `Lateral_dir_rampa_esteira_rolante_SOE.catPART`
**Quantidade:** 1 unidade

Lateral direita com alojamento para encaixe de uma chapa de PVC que forma a rampa da saída B da esteira.

---

### `Suporte_display_botoes_SOE.catPART`
**Quantidade:** 1 unidade

Suporte para o display LCD e os botões START e STOP.

---

## Peças do Subsistema de Sensoriamento, Atuação e Eletrônica
*Autor: Felipe de Castro*

---

### `Cancela_servo.catPART`
**Quantidade:** 1 unidade

Estrutura fixada ao eixo do servo motor responsável por guiar o objeto sobre a esteira para a saída B.

---

### `Suporte_Servo.catPART`
**Quantidade:** 1 unidade

Peça de fixação do servo motor. Este suporte é colado sobre a mesa da esteira e posiciona o servo motor na altura e orientação necessárias para suprir as demandas do escopo do projeto.

---

### `Suporte_STlink.catPART`
**Quantidade:** 1 unidade

Suporte para fixação do ST-Link (programador e debugger do STM32) no corpo da esteira.

---

### `Suporte_laser_c_ajuste_focal.catPART`
**Quantidade:** 3 unidades

Suporte do laser com ajuste focal para o sensor laser. Serve para alinhar o laser ao LDR e deve ser fixado na mesa da esteira com bom alinhamento entre os dois dispositivos. Cada sensor disposto na mesa da esteira possui um suporte de laser.

---

### `Suporte_LDR.catPART`
**Quantidade:** 3 unidades

Suporte do LDR. Serve para alinhar o LDR ao laser e deve ser fixado na mesa da esteira com bom alinhamento entre os dois dispositivos. Cada sensor na mesa possui um suporte de LDR.

---

### `Suporte_laser_Rampa.catPART`
**Quantidade:** 1 unidade

Suporte do laser para a rampa. É colado à lateral da rampa e cria um ponto de fixação por parafuso que prende o conjunto à base da esteira. Deve ser colado alinhado ao suporte do LDR da rampa.

---

### `Suporte_LDR_sensor_Rampa.catPART`
**Quantidade:** 1 unidade

Suporte do LDR para a rampa. É colado à lateral da rampa e cria um ponto de fixação por parafuso que prende o conjunto à base da esteira. Deve ser colado alinhado ao suporte do laser da rampa.

---

### `Suporte_flash_esteira.catPART`
**Quantidade:** 2 unidades

Suporte para a fita de LED que ilumina o objeto na região de leitura do código QR.

---

### `Suporte_poste_camera.catPART`
**Quantidade:** 2 unidades

Suporte plástico que une os dois suportes do flash e forma a estrutura da câmera, fechando a região de leitura da esteira. São utilizadas duas peças para separar igualmente os dois postes do flash.

---

### `Suporte_camera_Esteira_Soe.catPART`
**Quantidade:** 1 unidade

Ponto de fixação da câmera. Deve ser colado sobre os suportes que formam a região de leitura de forma que a câmera fique alinhada com o sensor laser onde o objeto é posicionado sobre o tapete da esteira.

## Case de fixação do Raspberry Pi 3b

*Autor: Nilo - Usuário do MakerWorld*

O case de fixação do RBPi3B utilizado foi obtido através da plataforma Open Source *MakerWorld*, que é um site onde usuários da comunidade de impressão 3D compartilham seus p´roprios desenhos de forma aberta sem fim comercial.

A case foi desenhada inicialmente para o RBPi4 e após impressa foi modificada para abrir os alojamentos das portas USB e HDMI.

O case original pode ser encontrado no seguinte link <https://makerworld.com/pt/models/1500557-case-for-raspberry-pi-4-with-40mm-fan?from=search#profileId-1569716>

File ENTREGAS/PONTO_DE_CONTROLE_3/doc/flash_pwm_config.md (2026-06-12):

# Configuração do PWM do Flash — Esteira Separadora v3.0

## Visão geral

O flash da esteira é controlado pelo **TIM17 Canal 1** do STM32G070, gerando um PWM cuja frequência é alta o suficiente para eliminar flicker visível, enquanto o duty cycle varia continuamente para produzir o efeito de fade-in/fade-out durante o estado `STATE_WAIT_CLASSIFICATION`.

---

## 1. Clock base do STM32G070

O microcontrolador opera a **64 MHz**, configurado via PLL a partir do oscilador interno HSI de 16 MHz:

```
HSI = 16 MHz
PLLM = 1  →  VCO input  = 16 / 1 = 16 MHz
PLLN = 8  →  VCO output = 16 × 8 = 128 MHz
PLLR = 2  →  SYSCLK     = 128 / 2 = 64 MHz
```

Todos os timers do APB1 (incluindo TIM17) recebem o clock diretamente:

```
f_TIM17 = 64 MHz
```

---

## 2. Clock do timer após prescaler

O prescaler divide o clock do timer antes que ele alimente o contador. O valor configurado no registrador é **PSC = 63**, mas o divisor efetivo é PSC + 1:

```
Divisor = PSC + 1 = 63 + 1 = 64

f_contador = f_TIM17 / Divisor
f_contador = 64.000.000 / 64 = 1.000.000 Hz = 1 MHz
```

Cada tick do contador corresponde a **1 µs**.

---

## 3. Frequência do PWM

A frequência do PWM é determinada pelo período do contador, definido pelo registrador ARR (Auto-Reload Register). O contador conta de 0 até ARR e reinicia, logo o período tem ARR + 1 ticks:

```
f_PWM = f_contador / (ARR + 1)

ARR configurado = 999

f_PWM = 1.000.000 / (999 + 1)
f_PWM = 1.000.000 / 1000
f_PWM = 1000 Hz = 1 kHz
```

**Por que 1 kHz?** O limiar de fusão de flicker do olho humano está entre 50–100 Hz dependendo do brilho e da pessoa. A 50 Hz (configuração anterior) parte dos usuários ainda percebe o piscar. A 1 kHz o PWM é completamente imperceptível — o led parece uma fonte de luz contínua com brilho variável.

---

## 4. Resolução do duty cycle

Com ARR = 999, o CCR (Compare/Capture Register) pode assumir valores inteiros de 0 a 999, dando **1000 passos de resolução**:

```
Resolução = 1 / (ARR + 1) = 1 / 1000 = 0,1% por passo

Duty cycle = CCR / (ARR + 1) × 100%
```

Exemplos práticos:

| CCR  | Duty cycle |
|---|---|
| 0 | 0% |
| 50 | 5% |
| 500  | 50% |
| 950  | 95% |
| 999  | 99,9% |

---

## 5. Limites do sweep

Os defines `FLASH_SWEEP_MIN` e `FLASH_SWEEP_MAX` estabelecem o piso e o teto do fade, evitando que o flash apague completamente ou fique em brilho máximo constante:

```c
#define FLASH_SWEEP_MIN  50    // duty mínimo = 50/1000 = 5%
#define FLASH_SWEEP_MAX  950   // duty máximo = 950/1000 = 95%
```

O piso de 5% garante que o flash nunca apague completamente durante a classificação (a câmera sempre tem alguma iluminação). O teto de 95% evita saturação da câmera no pico.

---

## 6. Velocidade e cadência do sweep

O sweep triangular avança `FLASH_SWEEP_STEP` unidades de CCR a cada `FLASH_SWEEP_PERIOD` milissegundos:

```c
#define FLASH_SWEEP_STEP    5    // passo por intervalo (em unidades de CCR)
#define FLASH_SWEEP_PERIOD  20   // intervalo entre passos (em ms)
```

### Cálculo do tempo de um ciclo completo (min → max → min)

```
Excursão total = FLASH_SWEEP_MAX - FLASH_SWEEP_MIN
               = 950 - 50 = 900 unidades de CCR

Passos por semiciclo = Excursão / STEP = 900 / 5 = 180 passos

Tempo por semiciclo = 180 × PERIOD = 180 × 20 ms = 3600 ms

Tempo de ciclo completo = 2 × 3600 ms = 7200 ms ≈ 7,2 segundos
```

Um ciclo completo de fade-in seguido de fade-out leva aproximadamente **7,2 segundos**, produzindo o efeito de "respiração" lenta semelhante ao standby de dispositivos Apple.

### Tabela de cadências possíveis

Para ajuste futuro, mantendo `STEP = 5`:

| PERIOD (ms) | Ciclo completo |
|---|---|
| 10 | ~3,6 s |
| 20 | ~7,2 s (atual) |
| 30 | ~10,8 s |
| 40 | ~14,4 s |

Para ajuste via `STEP`, mantendo `PERIOD = 20 ms`:

| STEP | Ciclo completo |
|---|---|
| 10 | ~3,6 s |
| 5 | ~7,2 s (atual) |
| 3 | ~12,0 s |
| 2 | ~18,0 s |

---

## 7. Resumo dos parâmetros configurados

| Parâmetro | Registrador | Valor  | Significado |
|---|---|---|---|
| Clock do timer | — | 64 MHz | SYSCLK sem divisão APB |
| Prescaler | PSC | 63 | Divisor efetivo = 64 → 1 MHz/tick  |
| Período do PWM | ARR | 999 | 1000 ticks → f_PWM = 1 kHz |
| Duty mínimo | CCR min | 50 | 5% de brilho |
| Duty máximo | CCR max | 950 | 95% de brilho |
| Passo do sweep | STEP | 5 | 0,5% de variação por intervalo |
| Intervalo | PERIOD | 20 ms  | Cadência de atualização do sweep |
| Ciclo de fade | — | ~7,2 s | Tempo de um ciclo min→max→min |

---

## 8. Onde cada parâmetro vive no código

```
MX_TIM17_Init()          →  PSC = 63, ARR = 999
USER CODE BEGIN PV       →  FLASH_SWEEP_MIN, FLASH_SWEEP_MAX,
                             FLASH_SWEEP_STEP, FLASH_SWEEP_PERIOD
flashPWM_Start()         →  inicializa CCR em FLASH_SWEEP_MIN e liga o PWM
flashPWM_Sweep()         →  atualiza o CCR a cada FLASH_SWEEP_PERIOD ms
flashPWM_Stop()          →  para o PWM e força o pino em LOW
STATE_WAIT_CLASSIFICATION →  entry action chama Start(), corpo chama Sweep()
```

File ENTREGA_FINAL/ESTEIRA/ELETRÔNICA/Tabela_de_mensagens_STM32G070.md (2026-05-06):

# Tabela de Mensagens — Firmware STM32G070 v3
> **Protocolo de quadro:**
> - **RX** (Raspberry Pi → STM32): `[0xAA][CMD]` ou `[0xAA][CMD][DATA]`
> - **TX** (STM32 → Raspberry Pi): `[0x90][PAYLOAD]` (sucesso), `[0x90][CMD][DATA]` (telemetria), ou `[0x91]` (erro)

---

## Tabela 1 — Dicionário Completo de Mensagens

| Símbolo | Byte | Direção | Tipo | Descrição |
|---|---|---|---|---|
| `START_FRAME_MSG` | `0xAA` | RX | Estrutura | Byte de início de quadro. Todo frame recebido deve começar com este byte; bytes fora de quadro são ignorados silenciosamente. |
| `CMD_OK_MSG` | `0x90` | TX | Estrutura | Byte de status positivo. Enviado como primeiro byte de qualquer resposta bem-sucedida, sempre seguido de um payload. |
| `CMD_ERR_MSG` | `0x91` | TX | Estrutura | Byte de status negativo. Enviado sozinho (1 byte) quando o comando recebido não é reconhecido. |
| `SYS_RDY_MSG` | `0x10` | RX | Handshake | Mensagem enviada pelo Raspberry Pi para iniciar o handshake. Só é aceita após todos os quatro sensores estarem operando na frequência esperada (200 Hz). |
| `SYS_INIT_MSG` | `0x01` | TX | Handshake | Payload de resposta ao handshake. Indica que o STM32 está inicializado. Enviado no quadro `[0x90][0x01]`, sempre seguido de `[0x90][0x11]` informando o modo inicial. |
| `MODE_FSM_MSG` | `0x11` | TX | Modo | Payload que informa que o modo ativo é `OP_MODE_FSM`. Enviado após handshake e após cada transição de modo. |
| `MODE_DEBUG_MSG` | `0x22` | TX | Modo | Payload que informa que o modo ativo é `OP_MODE_DEBUG`. Enviado após cada transição de modo. |
| `SW_RESET_MSG` | `0x33` | RX | Controle | Comando de reset por software. Processado com prioridade máxima (antes do toggle de modo e da FSM). O STM32 envia `[0x90][0x33]` e executa `NVIC_SystemReset()` após ~50 ms. |
| `ROUTE_A_RECEIVE_MSG` | `0xDA` | RX | FSM | Comando enviado pelo Raspberry Pi ordenando o encaminhamento do objeto para a Rota A. Válido apenas no estado `STATE_WAIT_CLASSIFICATION`. |
| `ROUTE_B_RECEIVE_MSG` | `0xDB` | RX | FSM | Comando enviado pelo Raspberry Pi ordenando o encaminhamento do objeto para a Rota B. Válido apenas no estado `STATE_WAIT_CLASSIFICATION`. |
| `OBJ_DETECTED_MSG` | `0xA0` | TX | FSM | Notificação espontânea de que o Sensor 1 detectou um objeto na entrada da esteira (transição `IDLE → OBJECT_DETECTED`). |
| `CLSS_REQUEST_MSG` | `0xC0` | TX | FSM | Solicitação de classificação enviada ao Raspberry Pi quando o objeto alcança o Sensor 2 (transição `OBJECT_DETECTED → WAIT_CLASSIFICATION`). O STM32 aguarda `0xDA` ou `0xDB` em resposta. |
| `ROUTE_A_FWRDNG_MSG` | `0xFA` | TX | FSM | Confirmação de que o objeto está sendo encaminhado para a Rota A. Enviado ao receber `0xDA`. |
| `ROUTE_B_FWRDNG_MSG` | `0xFB` | TX | FSM | Confirmação de que o objeto está sendo encaminhado para a Rota B. Enviado ao receber `0xDB`. |
| `ROUTE_A_SCCSS_DLVRY_MSG` | `0xBA` | TX | FSM | Notificação de entrega bem-sucedida na Rota A. Disparado quando o Sensor 3 detecta a passagem do objeto. FSM retorna a `STATE_IDLE`. |
| `ROUTE_B_SCCSS_DLVRY_MSG` | `0xBB` | TX | FSM | Notificação de entrega bem-sucedida na Rota B. Disparado quando o Sensor 4 detecta a passagem do objeto. FSM retorna a `STATE_IDLE`. |
| `DEBUG_MODE_TOGGLE_MSG` | `0xDD` | RX | Modo | Alterna entre `OP_MODE_FSM` e `OP_MODE_DEBUG`. Processado com prioridade máxima (após `SW_RESET_MSG`, antes da FSM) em qualquer modo de operação. |
| `SENS_STATUS_MSG` | `0x55` | TX | Telemetria | Mensagem espontânea de telemetria dos sensores. Enviada apenas em `OP_MODE_DEBUG`, somente quando o STATUS_BYTE muda. Frame de 3 bytes: `[0x90][0x55][STATUS_BYTE]`. Bits 0–3 do STATUS_BYTE indicam o estado de SENS1–SENS4 respectivamente (1 = objeto detectado, 0 = feixe livre). Bits 4–7 reservados (0). |
| `LIGHT_EN_MSG` | `0xE1` | RX | Assíncrono (Debug) | Liga o flash/luminária (`FLASH_PIN` → HIGH). Válido apenas em `OP_MODE_DEBUG`. |
| `LIGHT_DISABLE_MSG` | `0xD1` | RX | Assíncrono (Debug) | Desliga o flash/luminária (`FLASH_PIN` → LOW). Válido apenas em `OP_MODE_DEBUG`. |
| `GATE_OPEN_MSG` | `0xE2` | RX | Assíncrono (Debug) | Abre a cancela movendo o servo para `openAngle` (45°). Válido apenas em `OP_MODE_DEBUG`. |
| `GATE_CLOSE_MSG` | `0xD2` | RX | Assíncrono (Debug) | Fecha a cancela movendo o servo para `closeAngle` (0°). Válido apenas em `OP_MODE_DEBUG`. |
| `STPR_EN_MSG` | `0xE3` | RX | Assíncrono (Debug) | Ativa o motor de passo no modo *follow steps* (eixo engajado, TIM6 habilitado). Válido apenas em `OP_MODE_DEBUG`. |
| `STPR_DISABLE_MSG` | `0xD3` | RX | Assíncrono (Debug) | Desativa o motor de passo com eixo livre (driver A4988 em SLEEP). Válido apenas em `OP_MODE_DEBUG`. |
| `SET_STPR_FORWARD_MSG` | `0xE4` | RX | Assíncrono (Debug) | Define o sentido de rotação do motor de passo como **frente** (`stepperDirInst = 0`). Válido apenas em `OP_MODE_DEBUG`. |
| `SET_STPR_BACKWARD_MSG` | `0xD4` | RX | Assíncrono (Debug) | Define o sentido de rotação do motor de passo como **trás** (`stepperDirInst = 1`). Válido apenas em `OP_MODE_DEBUG`. |
| `SET_STPR_TGT_STPS_MSG` | `0xE5` | RX | Assíncrono (Debug) | Inicia um quadro de 3 bytes. O byte `DATA` subsequente define a quantidade de passos alvo (`targetStepps`). É o único frame RX de 3 bytes (`[0xAA][0xE5][DATA]`). Válido apenas em `OP_MODE_DEBUG`. |

---

## Tabela 2 — Fluxo de Mensagens por Evento

> **Legenda de quadros completos:**
> - Quadro TX de sucesso (2 bytes): `[0x90][PAYLOAD]`
> - Quadro TX de telemetria (3 bytes): `[0x90][0x55][STATUS_BYTE]`
> - Quadro TX de erro (1 byte): `[0x91]`
> - Quadro RX padrão (2 bytes): `[0xAA][CMD]`
> - Quadro RX com dado (3 bytes): `[0xAA][0xE5][DATA]`

---

### Modo Normal — `OP_MODE_FSM`

#### Sequência de Inicialização (Handshake)

| # | Evento | Agente | Quadro Completo | Bytes (hex) | Descrição |
|---|---|---|---|---|---|
| 1 | Sensores prontos + RPi inicia handshake | RPi → STM32 | `[START][SYS_RDY]` | `AA 10` | Raspberry Pi sinaliza que está pronto. STM32 só aceita após todos os sensores medirem 200 Hz. |
| 2 | STM32 confirma inicialização | STM32 → RPi | `[CMD_OK][SYS_INIT]` | `90 01` | STM32 confirma sistema inicializado. |
| 3 | STM32 informa modo inicial | STM32 → RPi | `[CMD_OK][MODE_FSM]` | `90 11` | STM32 informa que inicia em `OP_MODE_FSM`. Loop de boot encerra. FSM inicia em `STATE_IDLE`. |

---

#### Ciclo Completo — Objeto encaminhado para Rota A

| # | Evento / Estado FSM | Agente | Quadro Completo | Bytes (hex) | Descrição |
|---|---|---|---|---|---|
| 1 | `IDLE` → Sensor 1 detecta objeto | STM32 → RPi | `[CMD_OK][OBJ_DETECTED]` | `90 A0` | STM32 notifica detecção. FSM avança para `STATE_OBJECT_DETECTED`. |
| 2 | `OBJECT_DETECTED` → Sensor 2 detecta objeto | STM32 → RPi | `[CMD_OK][CLSS_REQUEST]` | `90 C0` | STM32 para o motor e solicita classificação. FSM avança para `STATE_WAIT_CLASSIFICATION`. |
| 3 | RPi define destino: Rota A | RPi → STM32 | `[START][ROUTE_A]` | `AA DA` | Raspberry Pi envia o resultado da classificação por visão computacional. |
| 4 | STM32 confirma e encaminha para Rota A | STM32 → RPi | `[CMD_OK][ROUTE_A_FWD]` | `90 FA` | STM32 confirma, aciona servo (`closeAngle`), religa motor. FSM avança para `STATE_ROUTE_A`. |
| 5 | `ROUTE_A` → Sensor 3 detecta objeto | STM32 → RPi | `[CMD_OK][ROUTE_A_OK]` | `90 BA` | Entrega confirmada na Rota A. FSM retorna para `STATE_IDLE`. |

---

#### Ciclo Completo — Objeto encaminhado para Rota B

| # | Evento / Estado FSM | Agente | Quadro Completo | Bytes (hex) | Descrição |
|---|---|---|---|---|---|
| 1 | `IDLE` → Sensor 1 detecta objeto | STM32 → RPi | `[CMD_OK][OBJ_DETECTED]` | `90 A0` | STM32 notifica detecção. FSM avança para `STATE_OBJECT_DETECTED`. |
| 2 | `OBJECT_DETECTED` → Sensor 2 detecta objeto | STM32 → RPi | `[CMD_OK][CLSS_REQUEST]` | `90 C0` | STM32 para o motor e solicita classificação. FSM avança para `STATE_WAIT_CLASSIFICATION`. |
| 3 | RPi define destino: Rota B | RPi → STM32 | `[START][ROUTE_B]` | `AA DB` | Raspberry Pi envia o resultado da classificação por visão computacional. |
| 4 | STM32 confirma e encaminha para Rota B | STM32 → RPi | `[CMD_OK][ROUTE_B_FWD]` | `90 FB` | STM32 confirma, aciona servo (`openAngle`), religa motor. FSM avança para `STATE_ROUTE_B`. |
| 5 | `ROUTE_B` → Sensor 4 detecta objeto | STM32 → RPi | `[CMD_OK][ROUTE_B_OK]` | `90 BB` | Entrega confirmada na Rota B. FSM retorna para `STATE_IDLE`. |

---

#### Troca de Modo (qualquer estado)

| # | Evento | Agente | Quadro Completo | Bytes (hex) | Descrição |
|---|---|---|---|---|---|
| 1 | RPi solicita entrada em modo debug | RPi → STM32 | `[START][DEBUG_TOGGLE]` | `AA DD` | Pode ser enviado em qualquer ponto, em qualquer estado da FSM. |
| 2 | STM32 ecoa o comando recebido | STM32 → RPi | `[CMD_OK][DEBUG_TOGGLE]` | `90 DD` | Confirmação imediata do recebimento do frame. |
| 3 | STM32 informa modo ativo | STM32 → RPi | `[CMD_OK][MODE_DEBUG]` | `90 22` | Motor travado (`stepperStopEngaged`), flash apagado. LED pisca 6× rápido. |
| 4 | RPi solicita retorno ao modo FSM | RPi → STM32 | `[START][DEBUG_TOGGLE]` | `AA DD` | Mesmo comando, reenviado para alternar de volta. |
| 5 | STM32 ecoa o comando recebido | STM32 → RPi | `[CMD_OK][DEBUG_TOGGLE]` | `90 DD` | Confirmação imediata do recebimento do frame. |
| 6 | STM32 informa modo ativo | STM32 → RPi | `[CMD_OK][MODE_FSM]` | `90 11` | FSM reinicia em `STATE_IDLE`. LED acende 400 ms e apaga. |

---

#### Reset por Software (qualquer estado, qualquer modo)

| # | Evento | Agente | Quadro Completo | Bytes (hex) | Descrição |
|---|---|---|---|---|---|
| 1 | RPi solicita reset | RPi → STM32 | `[START][SW_RESET]` | `AA 33` | Processado com prioridade máxima, antes do toggle de modo e da FSM. |
| 2 | STM32 confirma e reinicia | STM32 → RPi | `[CMD_OK][SW_RESET]` | `90 33` | STM32 envia confirmação, aguarda ~50 ms para o frame sair pelo TX e executa `NVIC_SystemReset()`. |

---

### Modo Debug — `OP_MODE_DEBUG`

> Em modo debug a FSM fica suspensa. O STM32 responde exclusivamente a comandos assíncronos e envia telemetria de sensores espontaneamente.

#### Telemetria de Sensores (espontânea)

| # | Evento | Agente | Quadro Completo | Bytes (hex) | Descrição |
|---|---|---|---|---|---|
| 1 | STATUS_BYTE dos sensores muda | STM32 → RPi | `[CMD_OK][SENS_STATUS][STATUS_BYTE]` | `90 55 NN` | Enviado apenas quando o valor do STATUS_BYTE muda em relação ao anterior. `NN`: bit 0 = SENS1, bit 1 = SENS2, bit 2 = SENS3, bit 3 = SENS4 (1 = objeto detectado, 0 = feixe livre). Bits 4–7 reservados (0). |

#### Comandos Assíncronos

| # | Comando enviado | Agente | Quadro Completo | Bytes (hex) | Ação executada pelo STM32 | Resposta STM32 | Bytes (hex) |
|---|---|---|---|---|---|---|---|
| 1 | Liga luminária | RPi → STM32 | `[START][LIGHT_EN]` | `AA E1` | `FLASH_PIN` → HIGH | `[CMD_OK][LIGHT_EN]` | `90 E1` |
| 2 | Desliga luminária | RPi → STM32 | `[START][LIGHT_DIS]` | `AA D1` | `FLASH_PIN` → LOW | `[CMD_OK][LIGHT_DIS]` | `90 D1` |
| 3 | Abre cancela | RPi → STM32 | `[START][GATE_OPEN]` | `AA E2` | Servo → `openAngle` (45°) | `[CMD_OK][GATE_OPEN]` | `90 E2` |
| 4 | Fecha cancela | RPi → STM32 | `[START][GATE_CLOSE]` | `AA D2` | Servo → `closeAngle` (0°) | `[CMD_OK][GATE_CLOSE]` | `90 D2` |
| 5 | Ativa motor (eixo engajado) | RPi → STM32 | `[START][STPR_EN]` | `AA E3` | `stepperFollowSteps()` | `[CMD_OK][STPR_EN]` | `90 E3` |
| 6 | Desativa motor (eixo livre) | RPi → STM32 | `[START][STPR_DIS]` | `AA D3` | `stepperStopDisengaged()` | `[CMD_OK][STPR_DIS]` | `90 D3` |
| 7 | Define direção: frente | RPi → STM32 | `[START][STPR_FWD]` | `AA E4` | `stepperDirInst = 0` | `[CMD_OK][STPR_FWD]` | `90 E4` |
| 8 | Define direção: trás | RPi → STM32 | `[START][STPR_BCK]` | `AA D4` | `stepperDirInst = 1` | `[CMD_OK][STPR_BCK]` | `90 D4` |
| 9 | Define quantidade de passos | RPi → STM32 | `[START][STPR_TGT][DATA]` | `AA E5 NN` | `targetStepps = DATA` (`NN` = valor de 0–255) | `[CMD_OK][STPR_TGT]` | `90 E5` |
| 10 | Comando desconhecido | RPi → STM32 | `[START][???]` | `AA ??` | Nenhuma ação | `[CMD_ERR]` | `91` |

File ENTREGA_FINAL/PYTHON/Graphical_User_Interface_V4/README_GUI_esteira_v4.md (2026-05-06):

# Esteira Separadora — GUI v4.0

**Sistema de Controle com Interface Gráfica**
STM32G070 ↔ Raspberry Pi 3B · Firmware v3.0 · SOE 2026.1

Autores: Felipe de Castro · Paulo Caleb Fernandes da Silva

---

## Índice

1. [Visão Geral](#1-visão-geral)
2. [Requisitos](#2-requisitos)
3. [Instalação](#3-instalação)
4. [Como Executar](#4-como-executar)
5. [Estrutura da Interface](#5-estrutura-da-interface)
   - 5.1 [Barra Superior Compartilhada](#51-barra-superior-compartilhada)
   - 5.2 [Aba APLICACAO — FSM Automática](#52-aba-aplicacao--fsm-automática)
   - 5.3 [Aba DEBUG — Controle Assíncrono](#53-aba-debug--controle-assíncrono)
6. [Fluxo de Operação Normal (Aba APLICACAO)](#6-fluxo-de-operação-normal-aba-aplicacao)
7. [Protocolo de Comunicação UART](#7-protocolo-de-comunicação-uart)
   - 7.1 [Estrutura dos Frames](#71-estrutura-dos-frames)
   - 7.2 [Tabela de Comandos — GUI → STM32](#72-tabela-de-comandos--gui--stm32)
   - 7.3 [Tabela de Mensagens — STM32 → GUI](#73-tabela-de-mensagens--stm32--gui)
8. [Leitura e Interpretação de QR Codes](#8-leitura-e-interpretação-de-qr-codes)
9. [Sistema de Log](#9-sistema-de-log)
10. [Temas Visual (Claro / Escuro)](#10-temas-visual-claro--escuro)
11. [Máquina de Estados (FSM)](#11-máquina-de-estados-fsm)
12. [Arquitetura do Código](#12-arquitetura-do-código)
13. [Comportamento de Reconexão Automática](#13-comportamento-de-reconexão-automática)
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

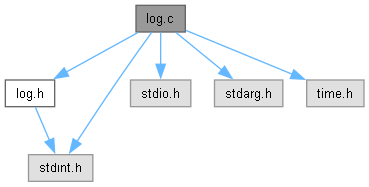
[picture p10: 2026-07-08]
ENTREGA_FINAL/GUI_c_LCD/docs/html/log_8c__incl.png

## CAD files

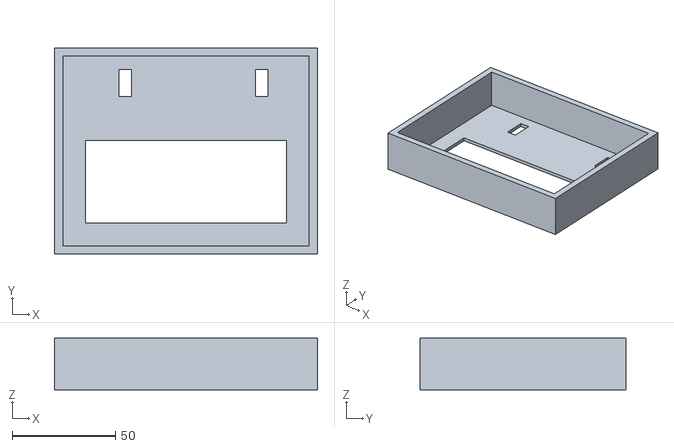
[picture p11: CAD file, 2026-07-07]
ENTREGA_FINAL/ESTEIRA/MECÂNICA/PEÇAS_STL/Suporte_display_botoes_SOE.stl
127.5 x 100.0 x 25.0

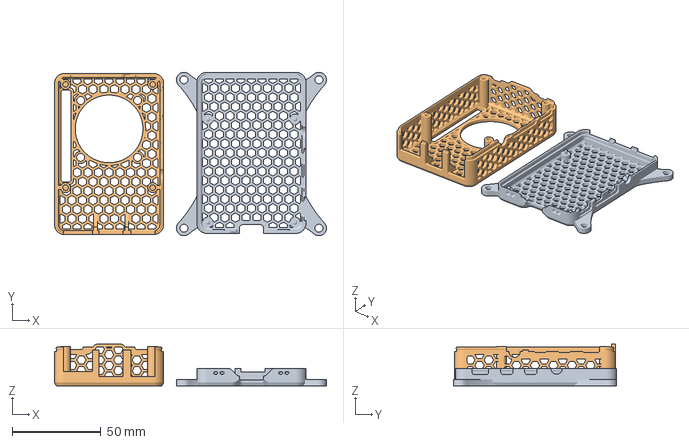
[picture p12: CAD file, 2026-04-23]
ENTREGA_FINAL/ESTEIRA/MECÂNICA/PEÇAS_STL/raspberry_pi_4_mesh_case_with_fan_hole_and_GPIO_hole.3mf
152.9 x 91.9 x 23.4 mm
raspberry_bottom.stl
Top_H20_Mesh_SM_Fan40_Screws_Hole_GPIO.stl

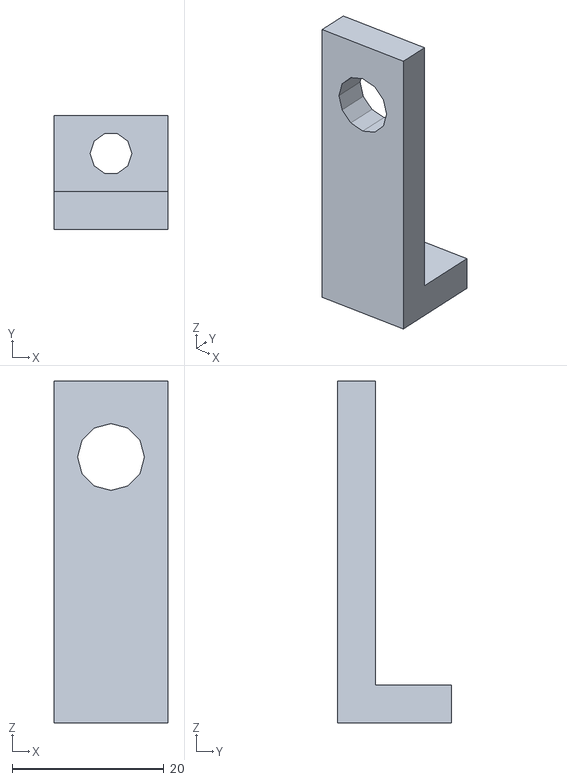
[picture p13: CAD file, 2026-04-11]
ENTREGA_FINAL/ESTEIRA/MECÂNICA/PEÇAS_STL/Suporte_laser_Rampa.stl
15.0 x 15.0 x 45.0

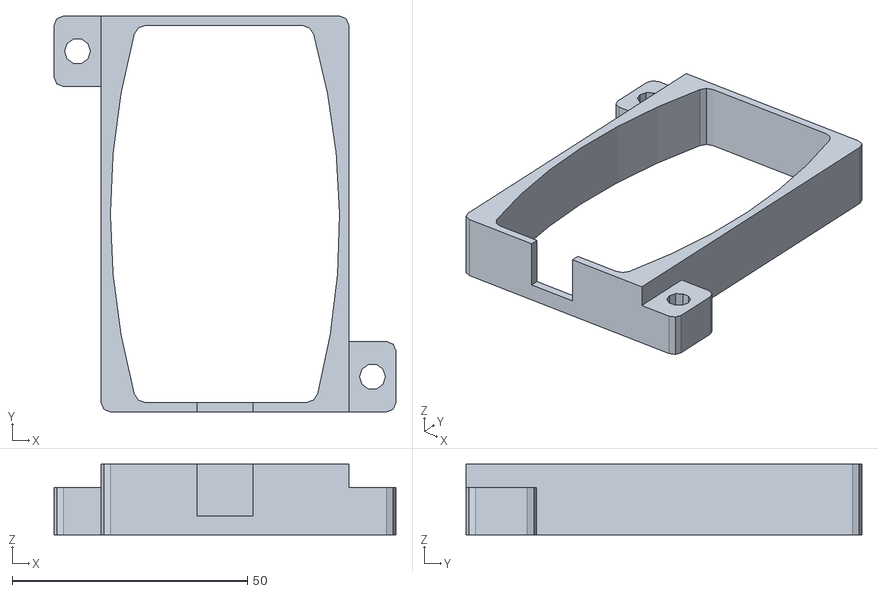
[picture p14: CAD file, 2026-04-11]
ENTREGA_FINAL/ESTEIRA/MECÂNICA/PEÇAS_STL/Suporte_STlink.stl
72.7 x 84.2 x 15.0

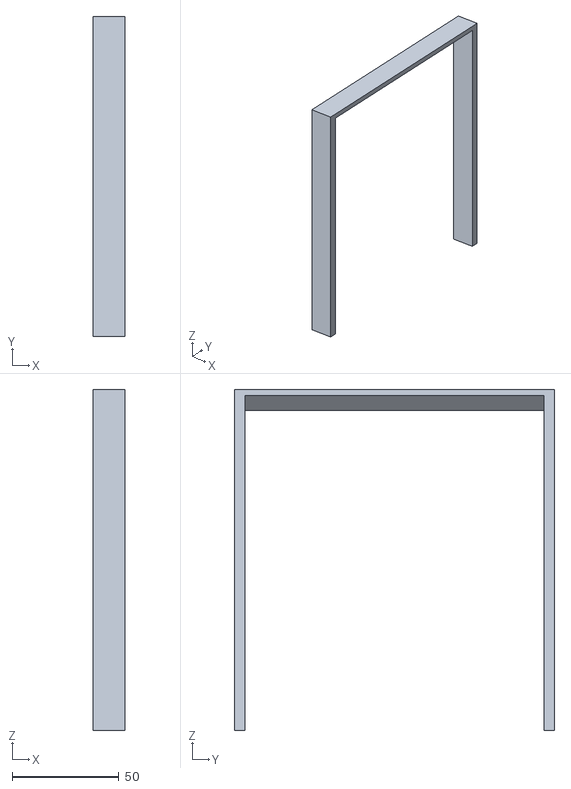
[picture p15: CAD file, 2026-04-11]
ENTREGA_FINAL/ESTEIRA/MECÂNICA/PEÇAS_STL/Suporte_flash_esteira.stl
15.0 x 150.0 x 160.0

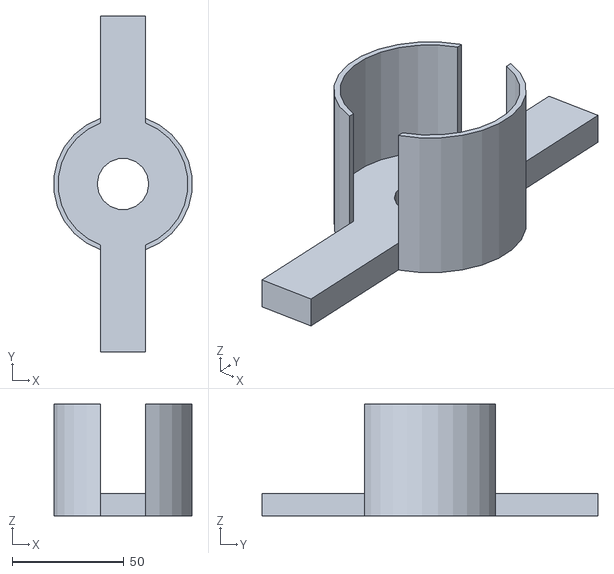
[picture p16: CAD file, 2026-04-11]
ENTREGA_FINAL/ESTEIRA/MECÂNICA/PEÇAS_STL/Suporte_camera_Esteira_SOE.stl
61.6 x 150.0 x 50.0

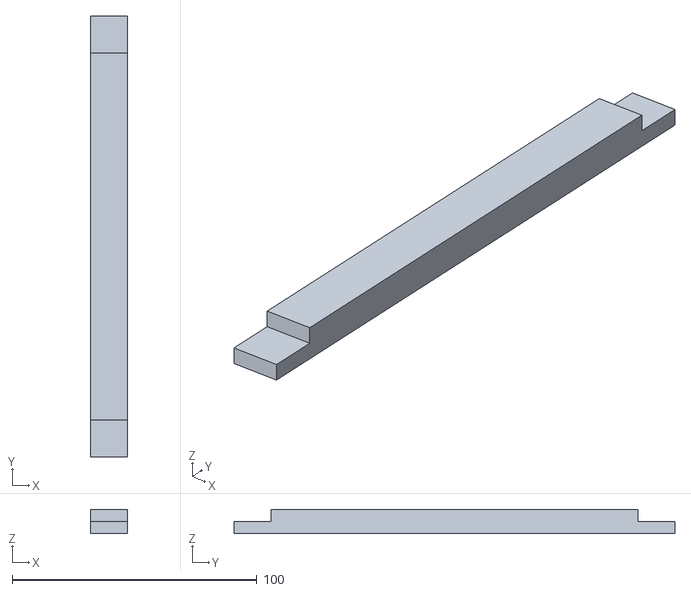
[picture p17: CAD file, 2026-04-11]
ENTREGA_FINAL/ESTEIRA/MECÂNICA/PEÇAS_STL/Suporte_poste_camera.stl
15.0 x 180.0 x 10.0

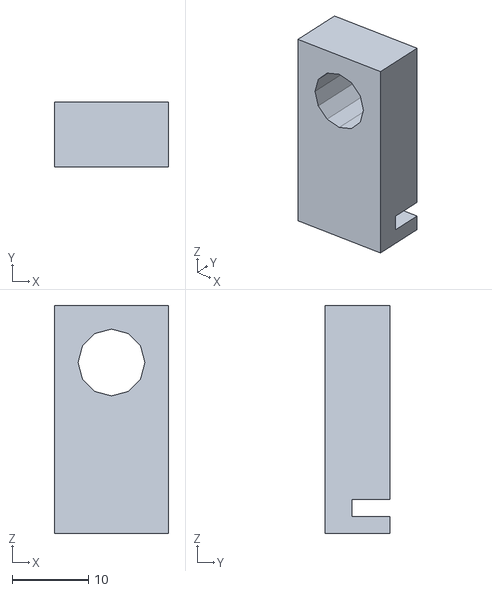
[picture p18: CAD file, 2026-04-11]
ENTREGA_FINAL/ESTEIRA/MECÂNICA/PEÇAS_STL/Suporte_laser_c_ajuste_focal.stl
15.0 x 8.50 x 30.0

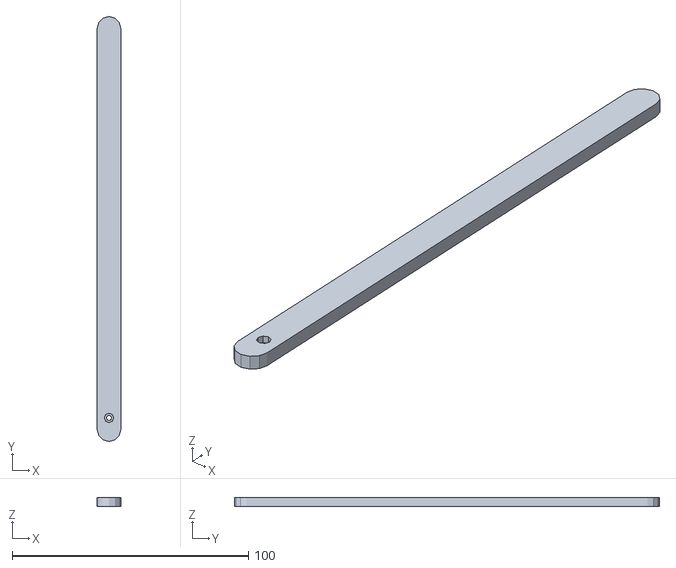
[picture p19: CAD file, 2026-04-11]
ENTREGA_FINAL/ESTEIRA/MECÂNICA/PEÇAS_STL/Cancela_servo.stl
10.0 x 180.0 x 4.00

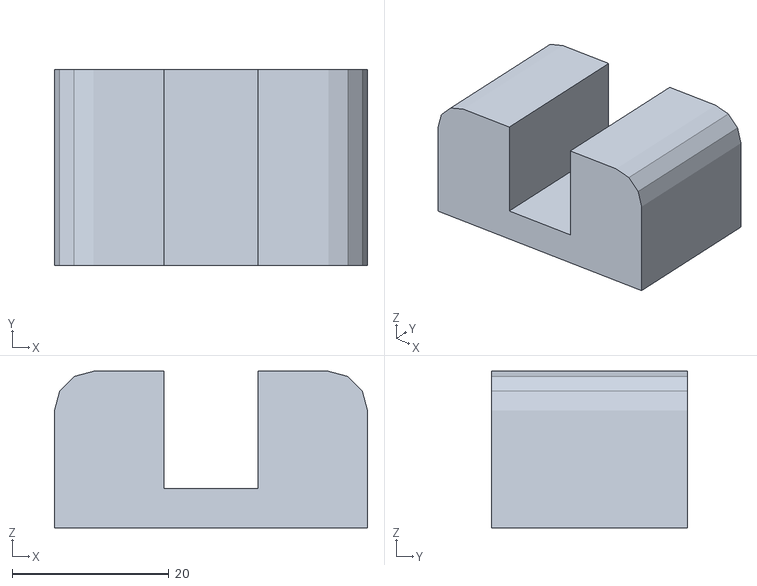
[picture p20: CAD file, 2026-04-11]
ENTREGA_FINAL/ESTEIRA/MECÂNICA/PEÇAS_STL/Suporte_Servo.stl
40.0 x 25.0 x 20.0

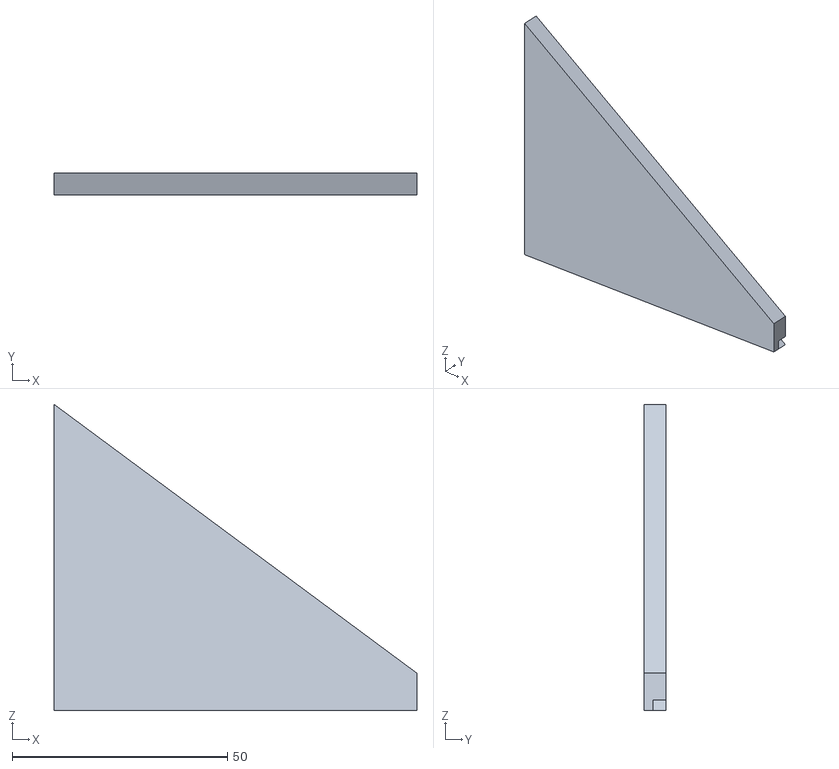
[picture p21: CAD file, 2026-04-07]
ENTREGA_FINAL/ESTEIRA/MECÂNICA/PEÇAS_STL/Lateral_esq_rampa_esteira_rolante_SOE.stl
84.4 x 5.00 x 71.2

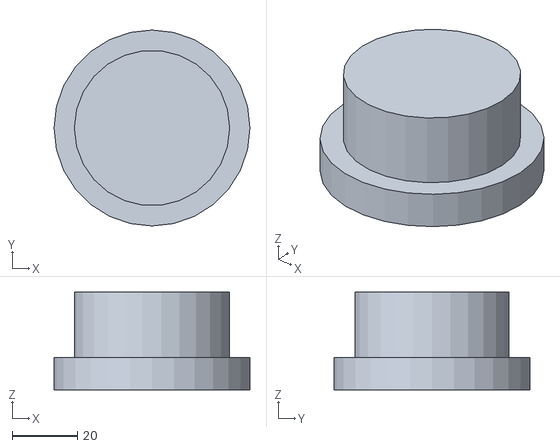
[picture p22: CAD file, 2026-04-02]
ENTREGA_FINAL/ESTEIRA/MECÂNICA/PEÇAS_STL/Tampa_Rolo_Motor_Esteira_Rolante_SOE.stl
60.0 x 60.0 x 30.0

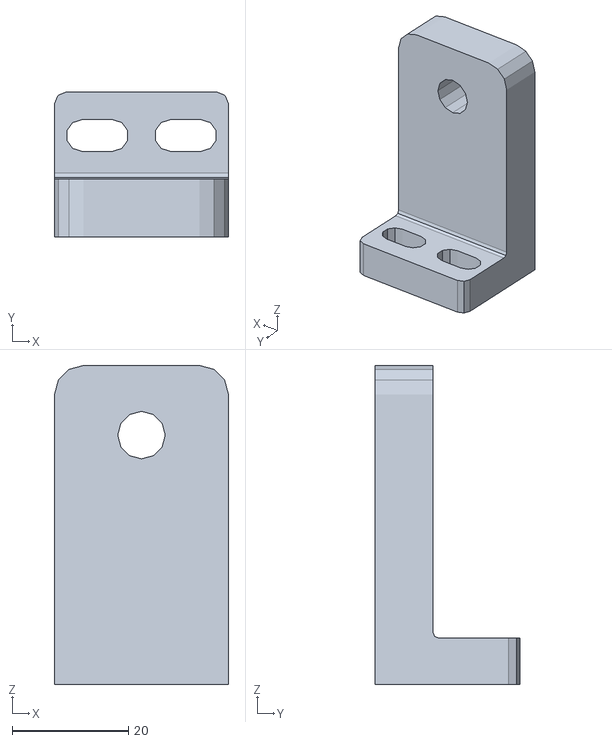
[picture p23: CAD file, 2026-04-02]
ENTREGA_FINAL/ESTEIRA/MECÂNICA/PEÇAS_STL/Suporte_Parafuso_Esteira_Rolante_SOE.stl
30.0 x 25.0 x 55.0

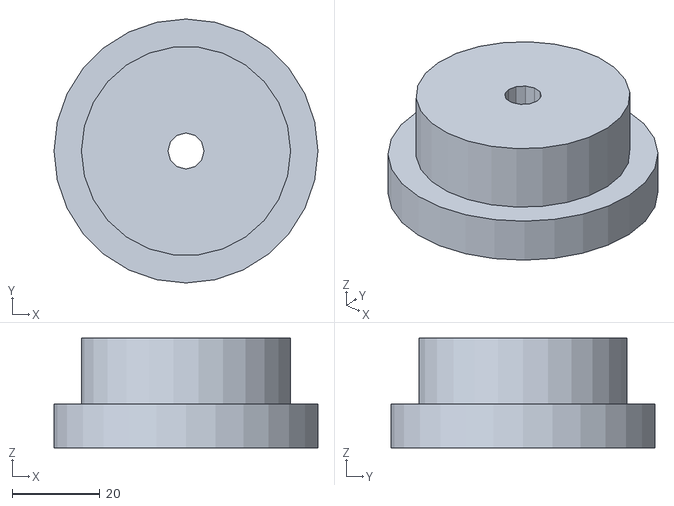
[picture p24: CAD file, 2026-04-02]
ENTREGA_FINAL/ESTEIRA/MECÂNICA/PEÇAS_STL/Tampa_Rolo_Rolamento_esteira_rolante_SOE.stl
60.0 x 60.0 x 25.0

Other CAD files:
ENTREGA_FINAL/ESTEIRA/MECÂNICA/PEÇAS_STL/Suporte_LDR.stl
ENTREGA_FINAL/ESTEIRA/MECÂNICA/PEÇAS_STL/Suporte_LDR_sensor_Rampa.stl
ENTREGA_FINAL/ESTEIRA/MECÂNICA/PEÇAS_STL/laterial_dir_rampa_Esteira_rolante_SOE.stl
ENTREGA_FINAL/ESTEIRA/MECÂNICA/PEÇAS_STL/Wood_stitches_Esteira_Rolante_SOE.stl
ENTREGA_FINAL/ESTEIRA/MECÂNICA/PEÇAS_CALEB/Apoio_Base_Esteira_Rolante_SOE.CATPart
ENTREGA_FINAL/ESTEIRA/MECÂNICA/PEÇAS_CALEB/Lateral_esq_rampa_esteira_rolante_SOE.CATPart
ENTREGA_FINAL/ESTEIRA/MECÂNICA/PEÇAS_CALEB/Suporte_Motor_Esteira_Rolante_SOE.CATPart
ENTREGA_FINAL/ESTEIRA/MECÂNICA/PEÇAS_CALEB/Suporte_Parafuso_Esteira_Rolante_SOE.CATPart
ENTREGA_FINAL/ESTEIRA/MECÂNICA/PEÇAS_CALEB/Suporte_display_botoes_SOE.CATPart
ENTREGA_FINAL/ESTEIRA/MECÂNICA/PEÇAS_CALEB/Suporte_mesa_Esteira_Rolante_SOE.CATPart
ENTREGA_FINAL/ESTEIRA/MECÂNICA/PEÇAS_CALEB/Tampa_Rolo_Motor_Esteira_Rolante_SOE.CATPart
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

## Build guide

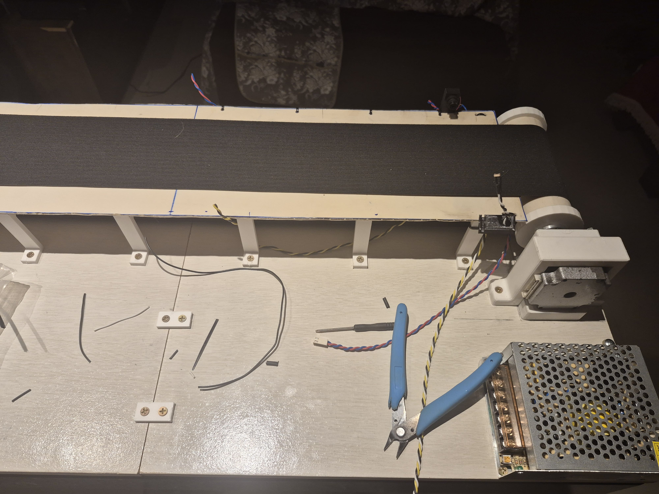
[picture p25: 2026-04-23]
ENTREGA_FINAL/ESTEIRA/Fotos_Esteira/MONTAGEM_SENSORES_LASER.jpg

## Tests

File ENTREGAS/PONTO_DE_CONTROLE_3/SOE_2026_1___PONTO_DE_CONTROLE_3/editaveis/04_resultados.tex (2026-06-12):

\section{Resultados Experimentais}\label{sec:resultados}

Os experimentos descritos nesta seção foram realizados com o objetivo de validar o funcionamento de cada subsistema fundamental da esteira, bem como a integração entre o microcontrolador STM32G070 e o Raspberry Pi 3B. Para cada subsistema, descreve-se o procedimento adotado, os resultados obtidos e, quando pertinente, as divergências observadas e suas possíveis causas.

\paragraph{Sensores \textit{laser}.}
Os quatro sensores operam conforme especificado. A lógica de detecção síncrona por ausência de portadora foi validada com sucesso --- ao interromper o feixe, as \textit{flags} internas (\texttt{SENS1\_flag} a \texttt{SENS4\_flag}) são acionadas corretamente, permitindo as transições de estado da FSM. A mudança das flags pode ser observada na Figura ~\ref{fig:sensor_telemetry}, na seção de software. Além disso, os testes de hardware (Figura ~\ref{fig:circ_laser}) mostram que os sensores funcionaram bem em testes de bancada, como ilustrado nas figuras ~\ref{fig:laser_sem_interrupção} e ~\ref{fig:laser_interrompido}, que mostram a transição do sinal entre laser sem interromper e interrompido.

\begin{figure}[H]
    \centering
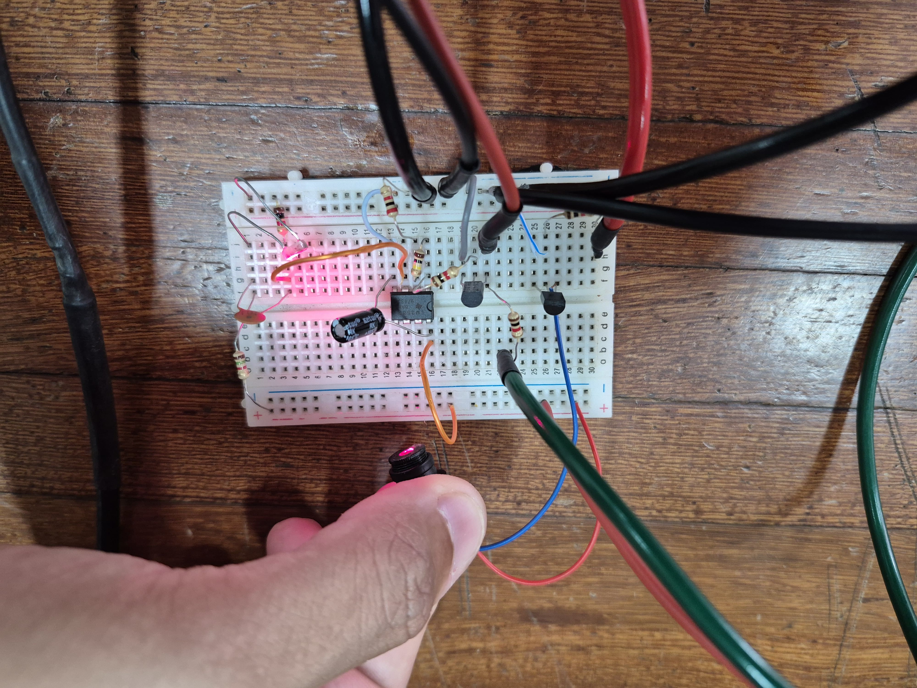
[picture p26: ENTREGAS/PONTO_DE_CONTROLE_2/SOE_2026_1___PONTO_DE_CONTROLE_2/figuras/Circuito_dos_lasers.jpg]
    
    \caption{Circuito dos lasers montado em bancada}
    \label{fig:circ_laser}
\end{figure}

\begin{figure}[H]
    \centering
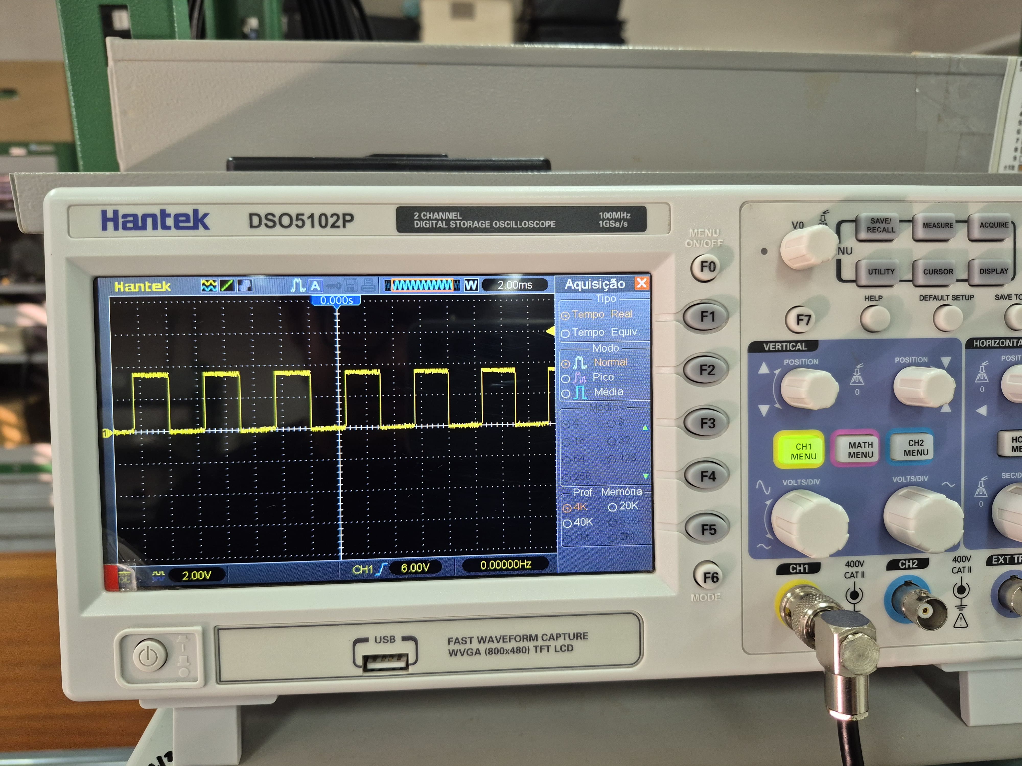
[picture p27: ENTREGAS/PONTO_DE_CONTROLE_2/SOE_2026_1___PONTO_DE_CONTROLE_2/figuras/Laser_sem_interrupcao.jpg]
    
    \caption{Laser sem interrupção}
    \label{fig:laser_sem_interrupção}
\end{figure}

\begin{figure}[H]
    \centering
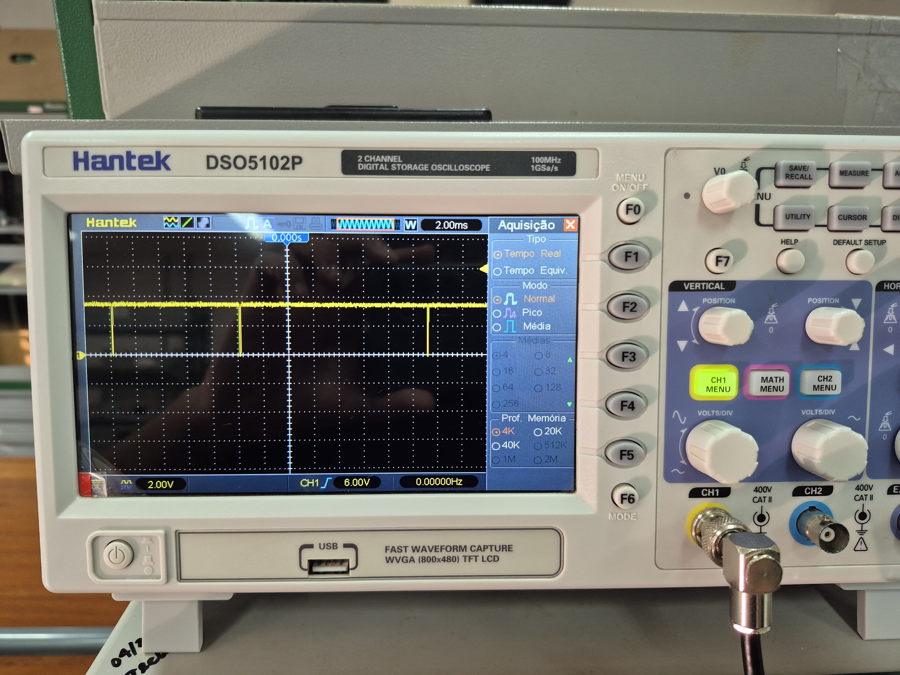
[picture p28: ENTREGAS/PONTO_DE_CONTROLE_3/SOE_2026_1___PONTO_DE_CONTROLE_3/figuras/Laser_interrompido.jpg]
    
    \caption{Laser interrompido}
    \label{fig:laser_interrompido}
\end{figure}

\paragraph{\textit{Flash} (luminária).}
O controle via PWM funciona corretamente, alterando a intensidade do brilho do \textit{flash} no modo FSM e ativando e desativado em resposta aos comandos assíncronos recebidos via UART, sem instabilidades observadas.

\paragraph{Motor de passo.}
O motor opera de forma estável em frequências mais baixas de acionamento. Os testes indicaram que o controle de velocidade por alteração do ARR do TIM6 funciona, porém com uma faixa operacional limitada --- comportamento esperado dadas as características físicas do motor de passo (torque \textit{versus} velocidade). Em razão disso, a velocidade de operação será mantida fixa no valor mínimo configurado (\texttt{STEPPER\_MIN\_VEL} $=$ 300\,passos/s), que corresponde a um período de interrupção do TIM6 de aproximadamente 1,67\,ms, calculado com base na configuração de \textit{prescaler} de 63 e \textit{clock} de 64\,MHz.

\paragraph{Servo motor.}
O servo motor ES08MA responde corretamente a qualquer valor de angulação dentro da faixa suportada (0° a 180°). Para a aplicação na esteira, os ângulos definidos no \textit{firmware} --- 0° para cancela fechada (Rota~A) e 45° para cancela aberta (Rota~B) --- foram validados e apresentaram o posicionamento mecânico desejado.

\paragraph{Dimensões do código QR.}
Observando o comportamento da câmera, foi possível verificar que um código QR com dimensões de 3×3\,cm conseguiu ser lido com maior facilidade do que um código QR com dimensões de 5×5\,cm. Além disso, para auxiliar na leitura do código, foi implementada uma rotina de \textit{fade-in/fade-out} do flash, garantindo que houvesse uma variação na luminosidade incidente no código QR. Essa variação auxiliou a leitura do código por permitir que o ajuste automático de saturação da \textit{webcam} se adaptasse à variação de luz ambiente, permitindo que ao menos um dos quadros capturados pelo sensor estivesse suficientemente nítido para a correta interpretação do código pelo algoritmo.

\paragraph{Instabilidades observadas na versão}

Durante o desenvolvimento e validação do sistema, foram identificadas instabilidades
que demandaram refinamentos ao longo do ciclo de implementação. No âmbito do
\textit{software}, três ocorrências foram tratadas: a interface de linha de comando
desenvolvida em C apresentava comportamento inconsistente em determinadas sequências
de operação, exigindo revisão da lógica de controle e do fluxo de execução; o
procedimento de \textit{reset} por software do STM32G070, acionado via comando
\texttt{SW\_RESET} pela interface, não respeitava o intervalo mínimo necessário para
a reinicialização completa do microcontrolador, causando falha no handshake subsequente;
por fim, foi identificada uma condição de corrida na etapa de inicialização do sistema,
em que o Raspberry Pi 3B tentava estabelecer comunicação antes que os periféricos do
STM32G070 estivessem devidamente configurados, resultando em perda do frame de
handshake.

Como perspectiva para o próximo ponto de controle, no âmbito do \textit{hardware}, prevê-se a
incorporação de um \textit{display} e de um botão físico à plataforma Raspberry Pi 3B.
Tais recursos permitiriam ao operador interagir diretamente com o sistema embarcado
sem depender de um terminal externo, tornando a operação mais autônoma e a interface
com o usuário mais intuitiva, características desejáveis para uma versão de produto
consolidada.

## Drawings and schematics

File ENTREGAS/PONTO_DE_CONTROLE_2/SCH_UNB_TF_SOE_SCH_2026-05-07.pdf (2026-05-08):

LM2596

# ALIMENTAÇÃO (LM2596S)

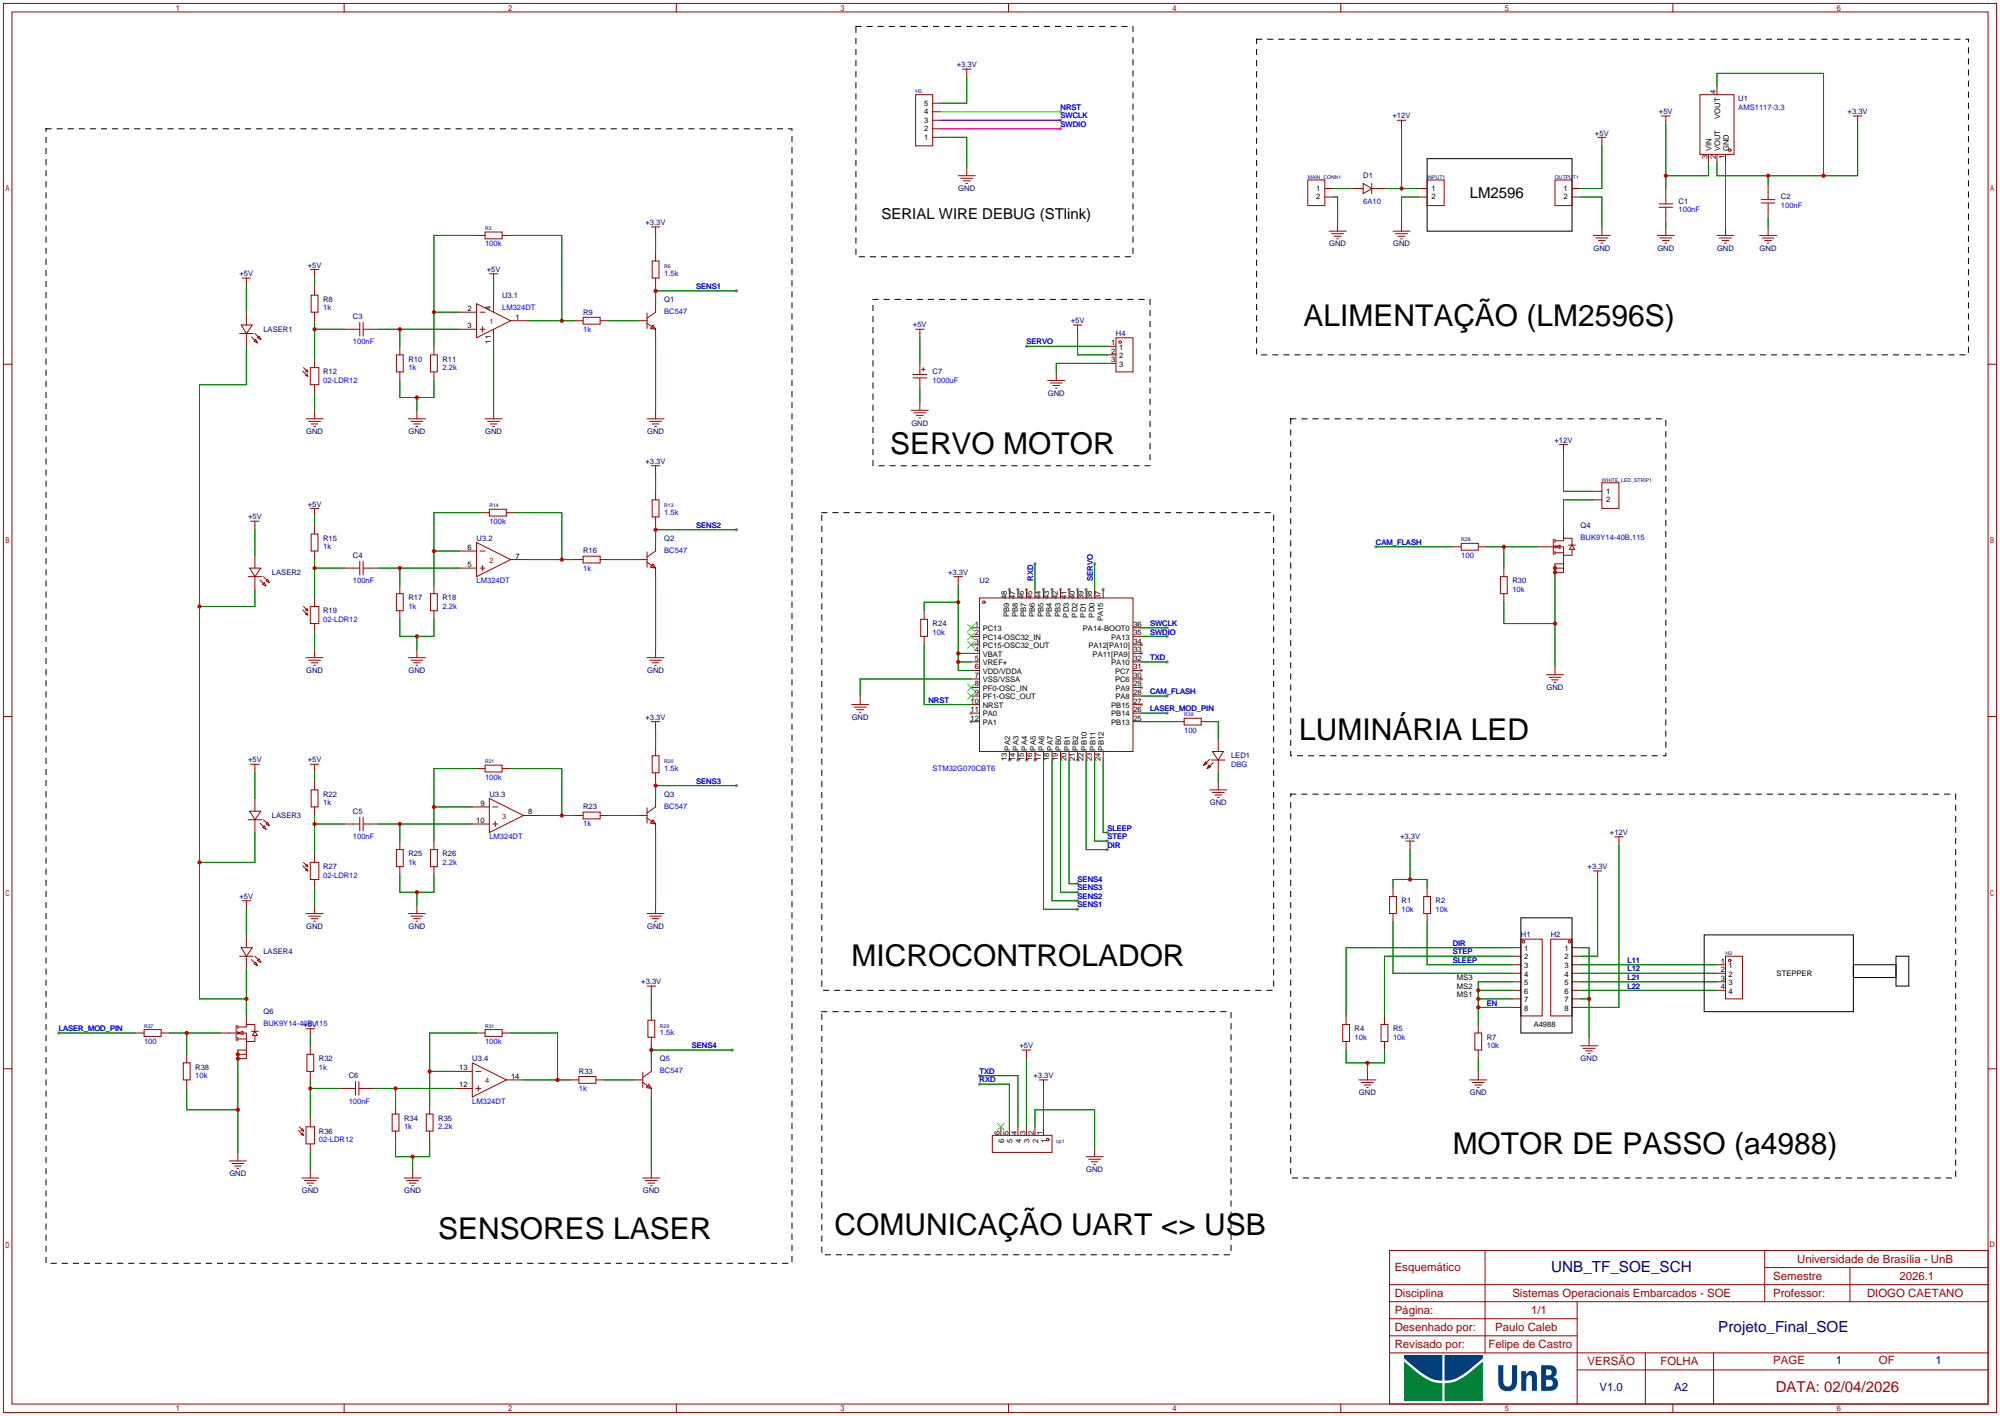
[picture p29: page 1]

SERIAL WIRE DEBUG (STlink)

Universidade de Brasília - UnB
Semestre

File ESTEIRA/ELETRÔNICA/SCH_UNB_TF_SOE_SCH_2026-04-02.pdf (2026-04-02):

LM2596

# ALIMENTAÇÃO (LM2596S)

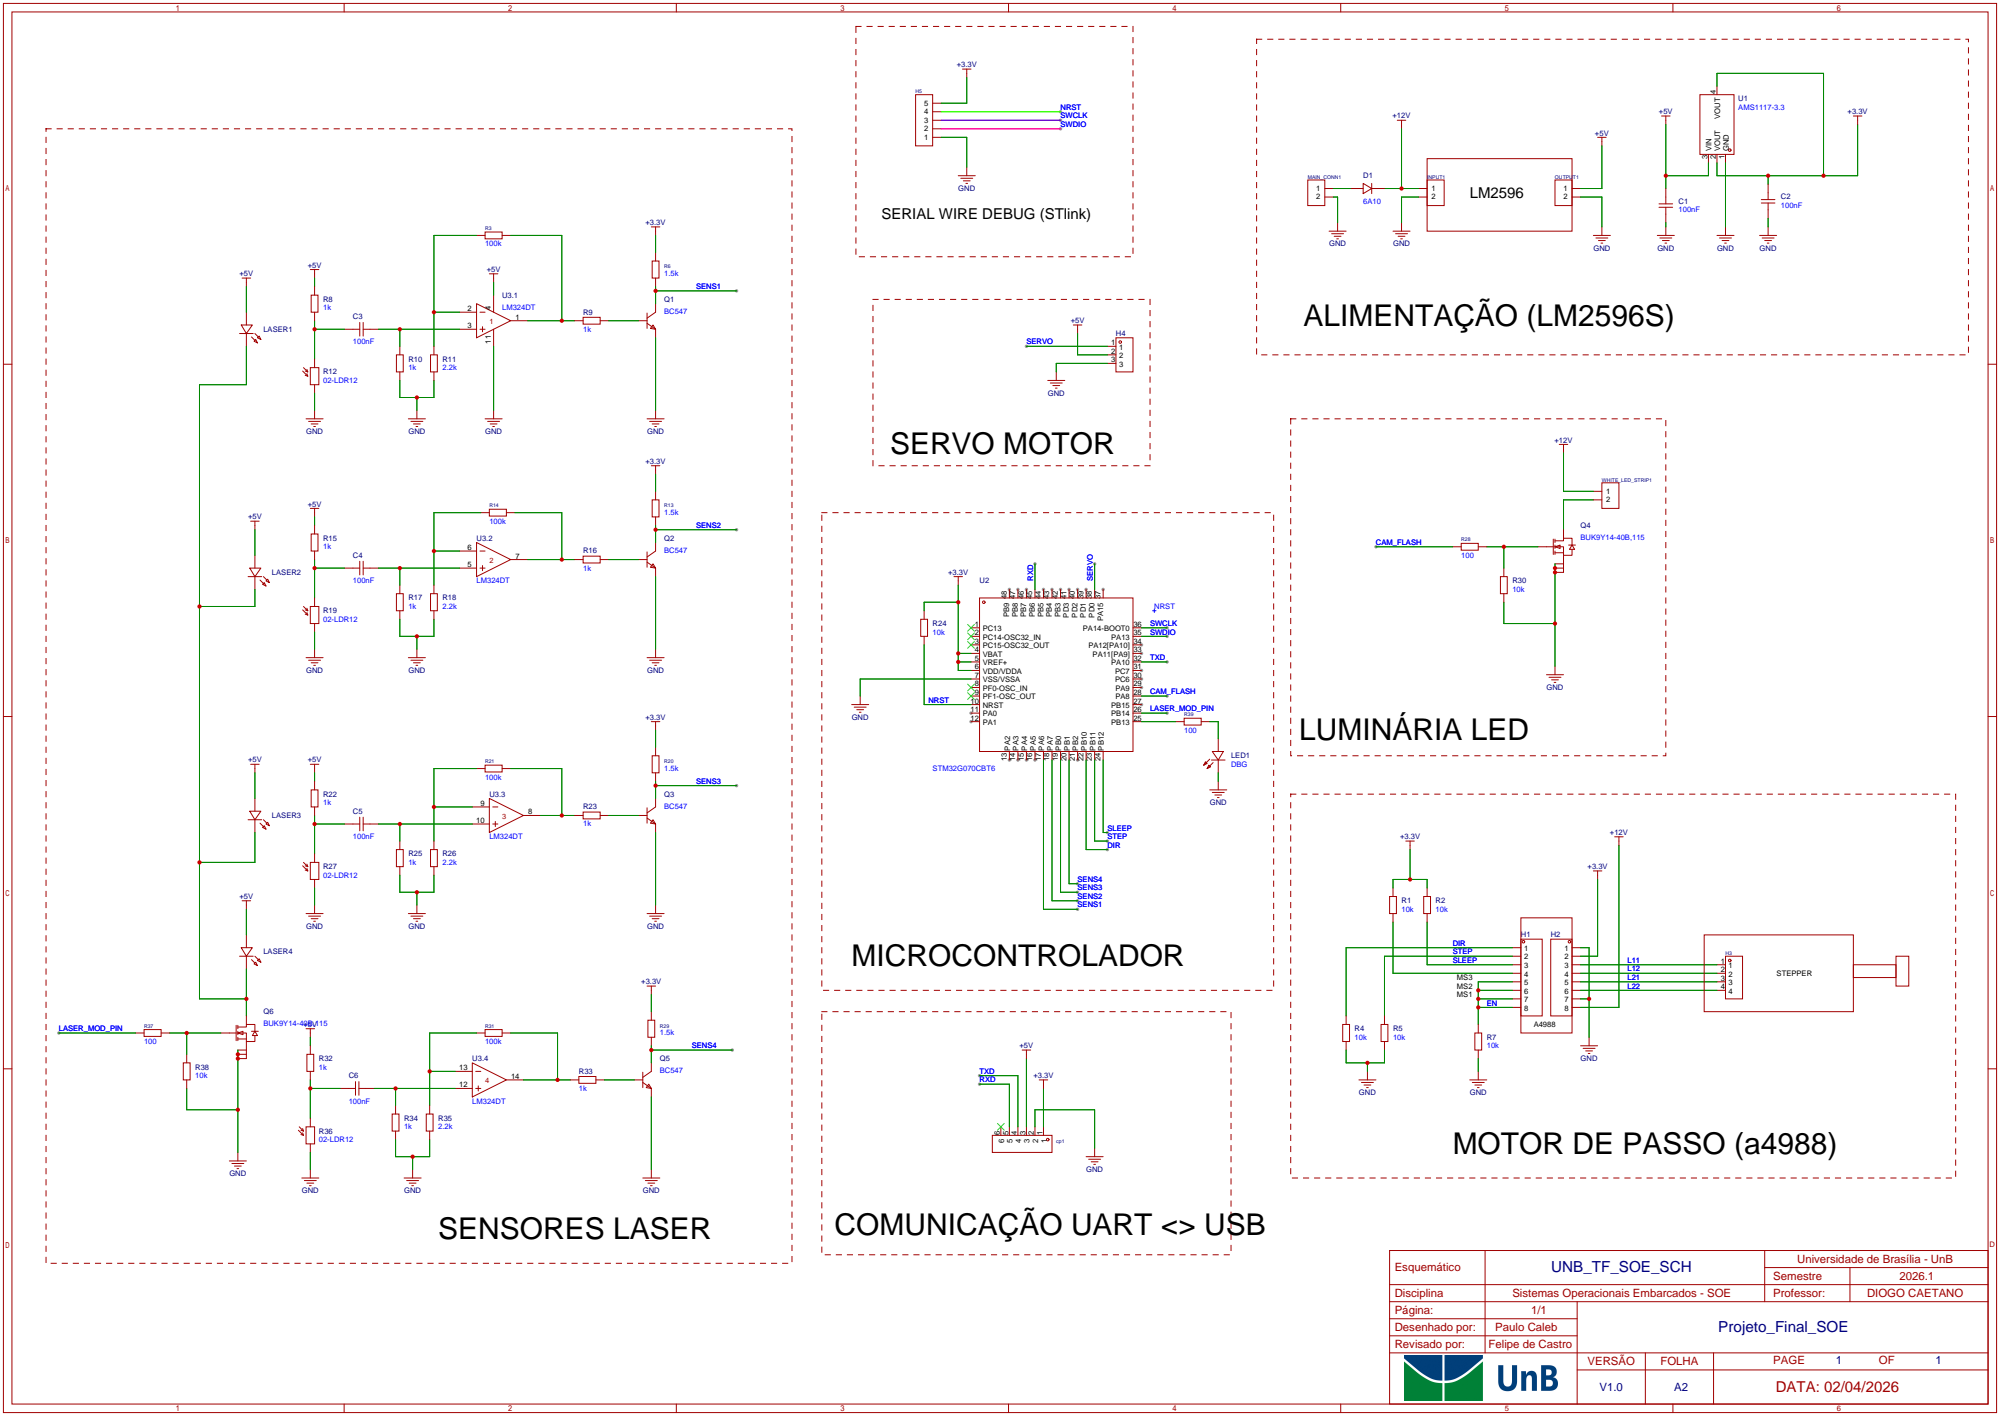
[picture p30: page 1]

SERIAL WIRE DEBUG (STlink)

Universidade de Brasília - UnB
Semestre

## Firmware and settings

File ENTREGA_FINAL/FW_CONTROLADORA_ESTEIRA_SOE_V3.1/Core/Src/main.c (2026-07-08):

/* USER CODE BEGIN Header */
/**
  ******************************************************************************
  * @file           : main.c
  * @brief          : Corpo do programa principal
  ******************************************************************************
  * 	TRABALHO FINAL - SISTEMAS OPERACIONAIS EMBARCADOS - SOE
  * 			FIRMWARE EMBARCADO - ESTEIRA SEPARADORA
  *
  * 		Semestre: 2026.1
  * 		Autor: Paulo Caleb Fernandes da Silva
  * 		Co-Autor: Felipe de Castro
  *
  * Objetivo: Gerenciar o Hardware embarcado na esteira para controlar os sensores
  *			  e atuadores previstos no esquemático, abrindo uma porta de comunicação UART
  * 		  para comunicação entre o hardware embarcado na esteira e o software embarcado
  * 	      no Raspberry pi 3;
  * 		  O sistema controlado pelo presente firmware não realiza a escolha do destino do
  * 		  objeto sobre a esteira, apenas segue comandos e executa a ação. O processamento
  * 		  de alto nível de abstração (imagem) ocorre no SBC Raspberry Pi 3b, que é responsável
  * 		  por definir a rota e comandar o hardware da esteira (controlado pelo presente firmware) por UART;
  *
  * 		  O presente firmware utiliza os Driversa HAL,
  * 		  disponibilizados industrialmente pela STMicroelectronics
  * 	      para a família de microcontroladores STM32.
  *
  * Informações técnicas:	Fcpu: 64MHz;
  * 			     		As GPIOs configuram os pinos de controle do driver do motor de passo;
  * 			    		O timer 15 é usado para a modulação dos lasers (PWM fixo);
  * 			    		O timer 3 é usado para o frequencímetro dos sensores (Input capture);
  * 			    		O timer16 é usado para o controle do servo motor (PWM com duty variável);
  * 			    		O timer 6 é usado para o controle do motor de passo (interrupção interna);
  * 			    		O timer 17 é usado para o PWM de brilho variável do flash (fade-in/fade-out);
  * @attention
  *
  * Copyright (c) 2026 STMicroelectronics.
  * All rights reserved.
  *
  * This software is licensed under terms that can be found in the LICENSE file
  * in the root directory of this software component.
  * If no LICENSE file comes with this software, it is provided AS-IS.
  *
  ******************************************************************************
  */
/* USER CODE END Header */
/* Includes ------------------------------------------------------------------*/
#include "main.h"

/* USER CODE BEGIN Includes */
#include <stdio.h>
/* USER CODE END Includes */

/* USER CODE BEGIN PD */

/*----------------------------QUADRO DE COMUNICAÇÃO---------------------------*/
// Estrutura do quadro
#define START_FRAME_MSG         0xAA
#define CMD_OK_MSG              0x90
#define CMD_ERR_MSG             0x91
// Handshake
#define SYS_RDY_MSG             0x10
#define SYS_INIT_MSG            0x01
// FSM - RX
#define ROUTE_A_RECEIVE_MSG     0xDA
#define ROUTE_B_RECEIVE_MSG     0xDB
// FSM - TX
#define OBJ_DETECTED_MSG        0xA0
#define CLSS_REQUEST_MSG        0xC0
#define ROUTE_A_FWRDNG_MSG      0xFA
#define ROUTE_B_FWRDNG_MSG      0xFB
#define ROUTE_A_SCCSS_DLVRY_MSG 0xBA
#define ROUTE_B_SCCSS_DLVRY_MSG 0xBB
// Controle assíncrono - RX
#define LIGHT_EN_MSG            0xE1
#define LIGHT_DISABLE_MSG       0xD1
#define GATE_OPEN_MSG           0xE2
#define GATE_CLOSE_MSG          0xD2
#define STPR_EN_MSG             0xE3
#define STPR_DISABLE_MSG        0xD3
#define SET_STPR_FORWARD_MSG    0xE4
#define SET_STPR_BACKWARD_MSG   0xD4
#define SET_STPR_TGT_STPS_MSG   0xE5
// Modo de operação
#define DEBUG_MODE_TOGGLE_MSG   0xDD
#define MODE_FSM_MSG            0x11
#define MODE_DEBUG_MSG          0x22
#define SW_RESET_MSG            0x33
// Telemetria de sensores
#define SENS_STATUS_MSG         0x55

/*----------------------------SERVO MOTOR-------------------------------------*/
#define SERVO_MIN_US 600	//Menor faixa de pulso do servo (em us)
#define SERVO_MAX_US 2300	//Maior faixa de pulso do servo (em us)
#define SERVO_MAX_ANGLE 180	//Mior ângulo do servo (em graus)
#define SERVO_MIN_ANGLE 0	//Menor ângulo do servo (em graus)
/*----------------------------MOTOR DE-PASSO----------------------------------*/
#define TIM6_FREQUENCY 1000000	//Frequencia de trabalho do timer 6
#define STEPPER_MAX_VEL 420	//Velocidade máxima do motor em passos/s (ajustar para valor real)
#define STEPPER_MIN_VEL 300//Velocidade mínima do motor em passos/s

/* USER CODE END PD */

TIM_HandleTypeDef htim3;
TIM_HandleTypeDef htim6;
TIM_HandleTypeDef htim15;
TIM_HandleTypeDef htim16;
TIM_HandleTypeDef htim17;
DMA_HandleTypeDef hdma_tim3_ch1;
DMA_HandleTypeDef hdma_tim3_ch2;
DMA_HandleTypeDef hdma_tim3_ch3;
DMA_HandleTypeDef hdma_tim3_ch4;

UART_HandleTypeDef huart2;

/* USER CODE BEGIN PV */
/*----------------------------SERVO MOTOR-------------------------------------*/
volatile uint8_t angle = 0;
uint8_t openAngle = 45;
uint8_t closeAngle = 0;
/*----------------------------MOTOR DE-PASSO----------------------------------*/
volatile uint8_t pulse_ctrl = 1; //flag que controla o disparo dos pulsos
volatile uint8_t movement_done_flag = 0; //Flag de movimento concluído do motor de passo
volatile uint32_t targetStepps = 0; //Globbal que armazena a quantidade de passos a serem dados pelo motor
volatile uint32_t stepperEN = 1; //Controla o acionamento do motor de passo
volatile uint8_t stepperDirInst = 0; //Define a direção do motor de passo instantâneamente
/*----------------------------SENSORES LASER----------------------------------*/
uint32_t sensUPDT = 10; //Período de captura dos sensores (em ms), esse valor deve ser no mínimo o dobro do período do sinal da portadora (TIM15)
uint32_t nowTick = 0;//Auxiliar para a contagem do tempo
//
uint32_t inputCapture_SENS1[2];//Captura duas bordas de descida do sensor 1
uint32_t SENS1_capture = 0;//Diferenca entre a ultima e a primeira capturas de bordas
uint32_t SENS1_freq = 0;//Frequencia instantânea do sensor
uint8_t  SENS1_flag = 0;//Flag de controle do sensor
//
uint32_t inputCapture_SENS2[2];//Captura duas bordas de descida do sensor 2
uint32_t SENS2_capture = 0;//Diferenca entre a ultima e a primeira capturas de bordas
uint32_t SENS2_freq = 0;//Frequencia instantânea do sensor
uint8_t  SENS2_flag = 0;//Flag de controle do sensor
//
uint32_t inputCapture_SENS3[2];//Captura duas bordas de descida do sensor 3
uint32_t SENS3_capture = 0;//Diferenca entre a ultima e a primeira capturas de bordas
uint32_t SENS3_freq = 0;//Frequencia instantânea do sensor
uint8_t  SENS3_flag = 0;//Flag de controle do sensor
//
uint32_t inputCapture_SENS4[2];//Captura duas bordas de descida do sensor 4
uint32_t SENS4_capture = 0;//Diferenca entre a ultima e a primeira capturas de bordas
uint32_t SENS4_freq = 0;//Frequencia instantânea do sensor
uint8_t  SENS4_flag = 0;//Flag de controle do sensor
//
uint8_t sensStatusByte     = 0x00; // STATUS_BYTE atual (bits 0-3 = flags SENS1-4)
uint8_t sensStatusByteLast = 0xFF; // Valor anterior; 0xFF força envio na primeira iteração

/*------------------------MÁQUINA DE ESTADOS FINITOS----------------------------------*/
typedef enum {
    STATE_IDLE = 0,
    STATE_OBJECT_DETECTED = 1,
    STATE_WAIT_CLASSIFICATION = 2,
    STATE_ROUTE_A = 3,
    STATE_ROUTE_B = 4,
	STATE_NONE = 255  // sentinela: força entry action na primeira execução
} FSM_State_t;

FSM_State_t state = STATE_IDLE;
FSM_State_t last_state = STATE_NONE; // força execução inicial

/*----------------------------MODO DE OPERAÇÃO--------------------------------*/
typedef enum {
    OP_MODE_FSM   = 0,  // Modo normal: FSM rodando
    OP_MODE_DEBUG = 1   // Modo debug: apenas comandos assíncronos
} OperationMode_t;

volatile OperationMode_t operationMode = OP_MODE_FSM; // Inicia em modo FSM

/*----------------------------RECEPÇÃO DE FRAME UART--------------------------*/
typedef enum {
    RX_WAIT_START = 0,  // Aguardando byte 0xAA
    RX_WAIT_CMD   = 1,  // Aguardando byte de comando
    RX_WAIT_DATA  = 2   // Aguardando byte de dado (só SET_STPR_TGT_STPS_MSG)
} RxFrameState_t;

volatile RxFrameState_t rxFrameState = RX_WAIT_START;
volatile uint8_t rxPendingCMD  = 0x00; // CMD do frame em montagem
volatile uint8_t rxFrameReady  = 0;    // Flag: frame completo pronto para processar
volatile uint8_t rxCMD         = 0x00; // CMD do último frame completo recebido
volatile uint8_t rxDATA        = 0x00; // DATA do último frame completo (se houver)
/*--------------------------FLAGS DE TRANSMISSÃO-------------------*/
//tx
uint8_t objDetectedMSG_flag = 0;//Flag de controle da mensagem de objeto detectado
uint8_t classificationRequestMSG_flag = 0;//Flag de controle da mensagem de solicitação de destino
uint8_t routeAforwardingMSG_flag = 0;//Flag de controle da mensagem de encaminhamento para a rota A
uint8_t routeBforwardingMSG_flag = 0;//Flag de controle da mensagem de encaminhamento para a rota B
uint8_t routeASuccesDeliveryMSG_flag = 0;//Flag de controle da mensagem de sucesso na entrega para a rota A
uint8_t routeBSuccesDeliveryMSG_flag = 0;//Flag de controle da mensagem de sucesso na entrega para a rota B


/*----------------------------FLASH PWM SWEEP---------------------------------*/
#define FLASH_SWEEP_MIN    50   // Duty mínimo (brilho mínimo ~5%)
#define FLASH_SWEEP_MAX    950  // Duty máximo (brilho máximo ~95%)
#define FLASH_SWEEP_STEP   10    // Incremento por chamada (velocidade do fade)
#define FLASH_SWEEP_PERIOD 20     // Intervalo entre passos em ms

uint32_t flashSweep_duty    = FLASH_SWEEP_MIN;
int8_t   flashSweep_dir     = 1;
uint32_t flashSweep_lastTick = 0;
/* USER CODE END PV */

void SystemClock_Config(void);
static void MX_GPIO_Init(void);
static void MX_DMA_Init(void);
static void MX_TIM15_Init(void);
static void MX_TIM3_Init(void);
static void MX_TIM16_Init(void);
static void MX_TIM6_Init(void);
static void MX_USART2_UART_Init(void);
static void MX_TIM17_Init(void);
/* USER CODE BEGIN PFP */
void getSensorsReadings();//Obtém a leitura dos sensores laser
void SetServoAngle(uint16_t angle); //Seta o angulo do motor de passo
void stepperMove(uint32_t steps, uint8_t direction);//Move o motor de passo uma quantidade de passos em um sentido definido
void stepperSetSpeed(uint32_t steppsPerSeconds);//Define a velocidade do motor de passo
void stepperStopDisengaged();//Para o motor com o eixo livre
void stepperStopEngaged();//Para o motor com o eixo travado
void stepperFollowSteps();//Asegue a quantidade de passos definida por stepperMove
void STEPPER_TIM6_ISR();//Interrupção responsável por controlar o motor de passo
void handleModeToggle(void); // Verifica e processa o comando de troca de modo
void handleAsyncCommands(void); // Executa os comandos assíncronos
void FSM();	//Executa a máquina de estados finitos
void sendFrame(uint8_t status, uint8_t payload); //Executa a montagem e o envio do quadro de TX para as mensagens espontâneas
void telemetryFrame(uint8_t status, uint8_t cmd, uint8_t data); //Executa a montagem do quadro de TX da telemetria dos sensores
void sendTelemetryData(void); //Faz a tomada de decisão para o envio dos dados de telemetria
void flashPWM_Start(void); // Inicia PWM do flash via TIM17
void flashPWM_Stop(void);           // Para PWM do flash
void flashPWM_Sweep(void);          // Atualiza fade-in/fade-out do flash
/* USER CODE END PFP */

/* USER CODE BEGIN 0 */
/*--------------------RECEPÇÃO DE FRAME UART------------------------------*/
uint8_t rxBuffer [5];
void HAL_UART_RxCpltCallback(UART_HandleTypeDef *huart){
	HAL_UART_Receive_IT(&huart2, rxBuffer, 1);
	    uint8_t byte = rxBuffer[0];

	    switch(rxFrameState){
	        case RX_WAIT_START:
	            if(byte == START_FRAME_MSG){        // 0xAA
	                rxFrameState = RX_WAIT_CMD;
	            }
	            // Qualquer outro byte fora de frame é ignorado silenciosamente
	            break;

	        case RX_WAIT_CMD:
	            rxPendingCMD = byte;
	            if(byte == SET_STPR_TGT_STPS_MSG){  // 0xE5 — espera DATA a seguir
	                rxFrameState = RX_WAIT_DATA;
	            } else {
	                // Frame de 2 bytes completo
	                rxCMD        = rxPendingCMD;
	                rxDATA       = 0x00;
	                rxFrameReady = 1;
	                rxFrameState = RX_WAIT_START;
	            }
	            break;

	        case RX_WAIT_DATA:
	            // Frame de 3 bytes completo
	            rxCMD        = rxPendingCMD;
	            rxDATA       = byte;
	            rxFrameReady = 1;
	            rxFrameState = RX_WAIT_START;
	            break;
	    }
}

/*--------------------TRANSMISSÃO DE FRAME UART------------------------------*/
/**
 * @brief Envia um frame TX padronizado.
 *
 * Resposta a comando RX:  sendFrame(CMD_OK_MSG,  cmdEco)   → [0x90][cmdEco]
 * Erro de reconhecimento: sendFrame(CMD_ERR_MSG, 0x00)     → [0x91]
 * Mensagem espontânea:    sendFrame(CMD_OK_MSG,  MSG_BYTE) → [0x90][MSG_BYTE]
 */
void sendFrame(uint8_t status, uint8_t payload){
    uint8_t frame[2];
    frame[0] = status;
    frame[1] = payload;

    if(status == CMD_ERR_MSG){
        HAL_UART_Transmit(&huart2, frame, 1, 1000); // CMD_ERR é single-byte
    } else {
        HAL_UART_Transmit(&huart2, frame, 2, 1000); // CMD_OK sempre com eco
    }
}


/**
 * @brief Envia frame de 3 bytes: [status][cmd][data]
 * Usado pela telemetria de sensores:
 *   telemetryFrame(CMD_OK_MSG, SENS_STATUS_MSG, statusByte)
 */
void telemetryFrame(uint8_t status, uint8_t cmd, uint8_t data){
    uint8_t frame[3];
    frame[0] = status;
    frame[1] = cmd;
    frame[2] = data;
    HAL_UART_Transmit(&huart2, frame, 3, 1000);
}

/**
 * @brief Envia telemetria dos 4 sensores laser.
 *
 * Só executa no modo Debug (OP_MODE_DEBUG).
 * Só envia quando o STATUS_BYTE mudar em relação à última transmissão,
 * evitando flood no barramento UART.
 *
 * STATUS_BYTE:
 *   bit 0 → SENS1_flag  (1 = objeto detectado, 0 = feixe livre)
 *   bit 1 → SENS2_flag
 *   bit 2 → SENS3_flag
 *   bit 3 → SENS4_flag
 *   bits 4-7 → reservados (0)
 *
 * Frame enviado: [0x90][0x55][STATUS_BYTE]
 */
void sendTelemetryData(void){
    if(operationMode != OP_MODE_DEBUG) return; // Só no modo debug

    sensStatusByte = (SENS1_flag & 0x01)        |
                     ((SENS2_flag & 0x01) << 1)  |
                     ((SENS3_flag & 0x01) << 2)  |
                     ((SENS4_flag & 0x01) << 3);

    if(sensStatusByte != sensStatusByteLast){   // Só envia se mudou
        telemetryFrame(CMD_OK_MSG, SENS_STATUS_MSG, sensStatusByte);
        sensStatusByteLast = sensStatusByte;
    }
}


/* USER CODE END 0 */

/**
  * @brief  The application entry point.
  * @retval int
  */
int main(void)
{

  /* MCU Configuration--------------------------------------------------------*/

  /* Reset of all peripherals, Initializes the Flash interface and the Systick. */
  HAL_Init();

  /* Configure the system clock */
  SystemClock_Config();

  /* USER CODE BEGIN SysInit */
  //Todos os SysInit foram incluídos nos trechos de configuração dos respectivos periféricos
  /* USER CODE END SysInit */

  /* Initialize all configured peripherals */
  MX_GPIO_Init();
  MX_DMA_Init();
  MX_TIM15_Init();
  MX_TIM3_Init();
  MX_TIM16_Init();
  MX_TIM6_Init();
  MX_USART2_UART_Init();
  MX_TIM17_Init();
  /* USER CODE BEGIN 2 */

  HAL_UART_Receive_IT(&huart2, rxBuffer, 1);

  //Aguarda a inicialização dos sensores
  uint8_t start = 0;
  uint8_t sensorsInit = 0;
  uint32_t dbgLedBlink = 0;
  while(!start){
	  stepperStopDisengaged();
	  getSensorsReadings();
	  if(SENS1_freq == 200 && SENS2_freq == 200 && SENS3_freq == 200 && SENS4_freq == 200 ){
		  sensorsInit = 1;
	  }
	  if(sensorsInit && rxFrameReady && rxCMD == SYS_RDY_MSG){
	      rxFrameReady = 0;
	      sendFrame(CMD_OK_MSG, SYS_INIT_MSG); //Informa ao RBPi3 que o sistema iniciou (fim do Handshake)
	      sendFrame(CMD_OK_MSG, MODE_FSM_MSG); //Por default inicia em modo FSM
	      HAL_GPIO_WritePin(dbgLED_GPIO_Port, dbgLED_Pin, GPIO_PIN_RESET);//Desliga o led
	      start = 1;
	  }
	  //Blink do LED de debug: pisca rápido se for identificado falha nos sensores, pisca devagar se estiver esperando o handshake do RBPi3
	  if(HAL_GetTick() - dbgLedBlink > (sensorsInit ? 500 : 100)){
			HAL_GPIO_TogglePin(dbgLED_GPIO_Port, dbgLED_Pin); // Assumindo LED no PA5 (comum em NUCLEO)
			dbgLedBlink = HAL_GetTick();
		}
  }
  /* USER CODE END 2 */

  /* Infinite loop */
  /* USER CODE BEGIN WHILE */
  while (1)
  {
	  getSensorsReadings(); //Obtém as leituras dos sensores
	  sendTelemetryData(); //Chamada da função para envio da telemetria (ocorre somente em modo debug)
	  handleModeToggle();      // 1º: verifica troca de modo (sempre, em qualquer modo)

	    if(operationMode == OP_MODE_DEBUG){
	        handleAsyncCommands(); // Modo debug: só comandos assíncronos
	        //SetServoAngle(angle); //Aciona o servo com stlink no modo debug
	    } else {
	        FSM();                 // Modo normal: FSM completa
	    }

	    //Verificação para a transmissão das mensagens
	    if(objDetectedMSG_flag){
	        objDetectedMSG_flag = 0;
	        sendFrame(CMD_OK_MSG, OBJ_DETECTED_MSG);
	    }
	    if(classificationRequestMSG_flag){
	        classificationRequestMSG_flag = 0;
	        sendFrame(CMD_OK_MSG, CLSS_REQUEST_MSG);
	    }
	    if(routeAforwardingMSG_flag){
	        routeAforwardingMSG_flag = 0;
	        sendFrame(CMD_OK_MSG, ROUTE_A_FWRDNG_MSG);
	    }
	    if(routeBforwardingMSG_flag){
	        routeBforwardingMSG_flag = 0;
	        sendFrame(CMD_OK_MSG, ROUTE_B_FWRDNG_MSG);
	    }
	    if(routeASuccesDeliveryMSG_flag){
	        routeASuccesDeliveryMSG_flag = 0;
	        sendFrame(CMD_OK_MSG, ROUTE_A_SCCSS_DLVRY_MSG);
	    }
	    if(routeBSuccesDeliveryMSG_flag){
	        routeBSuccesDeliveryMSG_flag = 0;
	        sendFrame(CMD_OK_MSG, ROUTE_B_SCCSS_DLVRY_MSG);
	    }
    /* USER CODE END WHILE */

    /* USER CODE BEGIN 3 */
  }
  /* USER CODE END 3 */
}

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
/* USER CODE BEGIN 4 */
//---------------------DESENVOLVIMENTO DAS FUNÇÕES-----------------------------*/
/*--------------------SENSORES LASER---------------------------------*/
/**
 * @brief Implementa um detector síncrono digital por aus~encia de portadora;
 * A portadora é gerada pelo timer 15, que pulsa o laser no sensor.
 * A frequência detectada pelo sensor é a mesma frequência da portadora;
 * Quando um objeto interrompe o feixe do laser, a portadora some, fato que é
 * indicado pela ausencia do sinal no ponto de interrupção do feixe.
 *
 * 	SENSn_freq - Frequencia medida no n-ésimo sensor
 * 	SENSn_flag - Bandeira de indicação do estado do feixe do laser sobre o sensor
 */
void getSensorsReadings(){
	//Base de tempo no loop infinito
    if(HAL_GetTick() - nowTick > sensUPDT){
		__HAL_TIM_SET_COUNTER(&htim3, 0);//Zera o contador do timer 3 para iniciar nova amostragem dos sensores
		//Sensor 1
		HAL_TIM_IC_Stop_DMA(&htim3, TIM_CHANNEL_1);
		HAL_TIM_IC_Start_DMA(&htim3, TIM_CHANNEL_1, inputCapture_SENS1, 2); //Inicia o DMA no canal 1, correspondente ao sensor 1 do sistema
		SENS1_capture = inputCapture_SENS1[1] - inputCapture_SENS1[0];
		if(SENS1_capture == 0){
			SENS1_flag = 1; //Encontrou um objeto na frente do sensor
			SENS1_freq = 0;
		} else {
			SENS1_freq = 1000000/SENS1_capture;
			SENS1_flag = 0;
		}
		inputCapture_SENS1[1] = 0;
		inputCapture_SENS1[0] = 0;
		//Sensor 2
		HAL_TIM_IC_Stop_DMA(&htim3, TIM_CHANNEL_2);
		HAL_TIM_IC_Start_DMA(&htim3, TIM_CHANNEL_2, inputCapture_SENS2, 2); //Inicia o DMA no canal 1, correspondente ao sensor 1 do sistema
		SENS2_capture = inputCapture_SENS2[1] - inputCapture_SENS2[0];
		if(SENS2_capture == 0){
			SENS2_flag = 1; //Encontrou um objeto na frente do sensor
			SENS2_freq = 0;
		} else {
			SENS2_freq = 1000000/SENS2_capture;
			SENS2_flag = 0;
		}
		inputCapture_SENS2[1] = 0;
		inputCapture_SENS2[0] = 0;
		//Sensor 3
		HAL_TIM_IC_Stop_DMA(&htim3, TIM_CHANNEL_3);
		HAL_TIM_IC_Start_DMA(&htim3, TIM_CHANNEL_3, inputCapture_SENS3, 2); //Inicia o DMA no canal 1, correspondente ao sensor 1 do sistema
		SENS3_capture = inputCapture_SENS3[1] - inputCapture_SENS3[0];
		if(SENS3_capture == 0){
			SENS3_flag = 1; //Encontrou um objeto na frente do sensor
			SENS3_freq = 0;
		} else {
			SENS3_freq = 1000000/SENS3_capture;
			SENS3_flag = 0;
		}
		inputCapture_SENS3[1] = 0;
		inputCapture_SENS3[0] = 0;
		//Sensor 4
		HAL_TIM_IC_Stop_DMA(&htim3, TIM_CHANNEL_4);
		HAL_TIM_IC_Start_DMA(&htim3, TIM_CHANNEL_4, inputCapture_SENS4, 2); //Inicia o DMA no canal 1, correspondente ao sensor 1 do sistema
		SENS4_capture = inputCapture_SENS4[1] - inputCapture_SENS4[0];
		if(SENS4_capture == 0){
			SENS4_flag = 1; //Encontrou um objeto na frente do sensor
			SENS4_freq = 0;
		} else {
		   SENS4_freq = 1000000/SENS4_capture;
		   SENS4_flag = 0;
		}
		inputCapture_SENS4[1] = 0;
		inputCapture_SENS4[0] = 0;
		//Atualiza a contagem do tick
		nowTick = HAL_GetTick();
    }
}
/*--------------------SERVO MOTOR-----------------------------------*/
/**
 * @brief Função para definição do angulo do servo motor ES08MA
 * Objetivo: mapear o valor do algulo em ticks do timeR;
 *
 * Utiliza o TIM16, que está gerando uma base de tempo de 1us.
 * O argumento da função é o ângulo desejadopara o servo, não retorna argumentos,
 * apenas define o duty cycle correspondente ao angulo desejado
 *
 */
void SetServoAngle(uint16_t angle){
	//Verificação da faixa
	if(angle > SERVO_MAX_ANGLE) angle = SERVO_MAX_ANGLE;
	if(angle < SERVO_MIN_ANGLE) angle = SERVO_MIN_ANGLE;
	//Mapeamento da fiaxa para os valores de ticks do timer
	uint32_t pulse_length = SERVO_MIN_US + ((uint32_t)angle*(SERVO_MAX_US-SERVO_MIN_US)/SERVO_MAX_ANGLE); //Realiza o mapeamento de acordo com as constantes do servo motor e a faixa 0-180 graus
	__HAL_TIM_SET_COMPARE(&htim16, TIM_CHANNEL_1, pulse_length);//Seta o duty de acorodo com o mapeamento do angulo desejado
}
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

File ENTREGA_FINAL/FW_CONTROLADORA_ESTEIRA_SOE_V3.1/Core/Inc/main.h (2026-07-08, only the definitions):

#define DIR_Pin GPIO_PIN_10
#define DIR_GPIO_Port GPIOB
#define STEP_Pin GPIO_PIN_11
#define STEP_GPIO_Port GPIOB
#define SLEEP_Pin GPIO_PIN_12
#define SLEEP_GPIO_Port GPIOB
#define dbgLED_Pin GPIO_PIN_13
#define dbgLED_GPIO_Port GPIOB
#define LASER_MOD_PIN_Pin GPIO_PIN_14
#define LASER_MOD_PIN_GPIO_Port GPIOB
#define SERVO_PIN_Pin GPIO_PIN_0
#define SERVO_PIN_GPIO_Port GPIOD
#define FLASH_PWM_Pin GPIO_PIN_1
#define FLASH_PWM_GPIO_Port GPIOD

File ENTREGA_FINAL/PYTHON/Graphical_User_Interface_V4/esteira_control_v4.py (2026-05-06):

"""
+=================================================================+
|   ESTEIRA SEPARADORA -- SISTEMA DE CONTROLE v4.0               |
|   STM32G070 <-> Raspberry Pi 3B  |  Firmware v3.0  |  SOE 2026 |
+=================================================================+

Dependencias:
    pip install pyserial opencv-python Pillow

Duas abas:
  APLICACAO  -- camera QR + FSM automatica
  DEBUG      -- controle assincrono completo + sensores

Regras de log:
  - Cada aba tem seu proprio log independente
  - Eventos UART so alimentam o log da aba ATIVA
  - Ao trocar de aba, o usuario e perguntado se deseja salvar o log
  - Arquivos: logFSM_NNN.txt  e  logDBG_NNN.txt
    onde NNN e a contagem de saves na sessao (001, 002, ...)
"""

import re
import threading
import queue
import time
import os
from datetime import datetime

import tkinter as tk
from tkinter import ttk, font as tkfont, messagebox

try:
    import serial
    import serial.tools.list_ports
    SERIAL_AVAILABLE = True
except Exception:
    SERIAL_AVAILABLE = False

try:
    import cv2
    CV2_AVAILABLE = True
except Exception:
    CV2_AVAILABLE = False

try:
    from PIL import Image, ImageTk
    PIL_AVAILABLE = True
except Exception:
    PIL_AVAILABLE = False

QR_AVAILABLE = CV2_AVAILABLE and PIL_AVAILABLE

# =============================================================================
#  PROTOCOLO COMPLETO (firmware v3.0)
# =============================================================================
START_FRAME      = 0xAA
CMD_OK           = 0x90
CMD_ERR          = 0x91
# Handshake
SYS_RDY          = 0x10
SYS_INIT         = 0x01
# FSM RX (GUI -> STM32)
ROUTE_A_SEND     = 0xDA
ROUTE_B_SEND     = 0xDB
# FSM TX (STM32 -> GUI)
OBJ_DETECTED     = 0xA0
CLSS_REQUEST     = 0xC0
ROUTE_A_FWD      = 0xFA
ROUTE_B_FWD      = 0xFB
ROUTE_A_OK       = 0xBA
ROUTE_B_OK       = 0xBB
# Controle assincrono RX
LIGHT_EN         = 0xE1
LIGHT_DIS        = 0xD1
GATE_OPEN        = 0xE2
GATE_CLOSE       = 0xD2
STPR_EN          = 0xE3
STPR_DIS         = 0xD3
STPR_FORWARD     = 0xE4
STPR_BACKWARD    = 0xD4
STPR_TGT_STPS    = 0xE5
# Modo
DEBUG_TOGGLE     = 0xDD
MODE_FSM_MSG     = 0x11
MODE_DEBUG_MSG   = 0x22
# v3.0
SW_RESET_MSG     = 0x33
SENS_STATUS_MSG  = 0x55

RX_NAMES = {
    SYS_INIT:        "SYS_INIT       (0x01)",
    OBJ_DETECTED:    "OBJ_DETECTED   (0xA0)",
    CLSS_REQUEST:    "CLSS_REQUEST   (0xC0)",
    ROUTE_A_FWD:     "ROUTE_A_FWD    (0xFA)",
    ROUTE_B_FWD:     "ROUTE_B_FWD    (0xFB)",
    ROUTE_A_OK:      "ROUTE_A_OK     (0xBA)",
    ROUTE_B_OK:      "ROUTE_B_OK     (0xBB)",
    MODE_FSM_MSG:    "MODE_FSM       (0x11)",
    MODE_DEBUG_MSG:  "MODE_DEBUG     (0x22)",
    SENS_STATUS_MSG: "SENS_STATUS    (0x55)",
    LIGHT_EN:        "LIGHT_EN       (0xE1 eco)",
    LIGHT_DIS:       "LIGHT_DIS      (0xD1 eco)",
    GATE_OPEN:       "GATE_OPEN      (0xE2 eco)",
    GATE_CLOSE:      "GATE_CLOSE     (0xD2 eco)",
    STPR_EN:         "STPR_EN        (0xE3 eco)",
    STPR_DIS:        "STPR_DIS       (0xD3 eco)",
    STPR_FORWARD:    "STPR_FORWARD   (0xE4 eco)",
    STPR_BACKWARD:   "STPR_BACKWARD  (0xD4 eco)",
    STPR_TGT_STPS:   "STPR_TGT_STPS  (0xE5 eco)",
    DEBUG_TOGGLE:    "DEBUG_TOGGLE   (0xDD eco)",
    ROUTE_A_SEND:    "ROUTE_A        (0xDA eco)",
    ROUTE_B_SEND:    "ROUTE_B        (0xDB eco)",
    SW_RESET_MSG:    "SW_RESET       (0x33 eco)",
}
TX_NAMES = {
    SYS_RDY:      "SYS_RDY        (0x10)",
    ROUTE_A_SEND: "ROUTE_A        (0xDA)",
    ROUTE_B_SEND: "ROUTE_B        (0xDB)",
    LIGHT_EN:     "LIGHT_EN       (0xE1)",
    LIGHT_DIS:    "LIGHT_DIS      (0xD1)",
    GATE_OPEN:    "GATE_OPEN      (0xE2)",
    GATE_CLOSE:   "GATE_CLOSE     (0xD2)",
    STPR_EN:      "STPR_EN        (0xE3)",
    STPR_DIS:     "STPR_DIS       (0xD3)",
    STPR_FORWARD: "STPR_FORWARD   (0xE4)",
    STPR_BACKWARD:"STPR_BACKWARD  (0xD4)",
    STPR_TGT_STPS:"STPR_TGT_STPS  (0xE5)",
    DEBUG_TOGGLE: "DEBUG_TOGGLE   (0xDD)",
    SW_RESET_MSG: "SW_RESET       (0x33)",
}
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

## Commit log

2026-04-02 População inicial do repositório
    Adição do README principal e das pastas dos pontos de controle com seus respectivos READMEs
2026-04-02 Reorganização da estrutura de pastas do repositório
    Inclusão da pasta com as credenciais do raspberry pi usado com SSH e criação da pasta "ENTREGAS", que concatena todas as entregas dos pontos de controle
2026-04-02 Primeiras peças mecânicas da estrutura da esteira
    .
    [Apoio_Base_Esteira_Rolante_SOE.CATPart, Wood_stitches_Esteira_Rolante_SOE.CATPart]
2026-04-02 STL das primeiras peças
    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
    [Apoio_Base_Esteira_Rolante_SOE.stl, Wood_stitches_Esteira_Rolante_SOE.stl]
2026-04-02 Adição da pasta Datasheets
    Contém o MCU que pretendemos utilizar, o driver de motor de passo e o servo motor
2026-04-02 Gerador de códigos QRs personalizados
2026-04-02 Adição da proposta de esquemático para a central eletrônica de controle de baixo nível
    Esquema elétrico do STM32 que irá controlar a esteira, falta fazer o diagrama de blocos num software de desenho ECAD (tirar do papel)
2026-04-02 Peças mecânicas para fixação do motor de passo
    Peças impressas durante a noite. Já estão fixando o motor. Pensando em criar uma pasta para colocar fotos do processo de construção
    [Suporte_Motor_Esteira_Rolante_SOE.CATPart, Trava_Suporte_Motor_Esteira_Rolante_SOE.CATPart]
2026-04-02 Inclusão dos .stl que foram impressos
    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
    [Suporte_Motor_Esteira_Rolante_SOE.stl, Trava_Suporte_Motor_Esteira_Rolante_SOE.stl]
2026-04-02 Tampas dos canos que formam os rolos da esteira
    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
    [Tampa_Rolo_Motor_Esteira_Rolante_SOE.CATPart, Tampa_Rolo_Rolamento_esteira_rolante_SOE.CATPart]
2026-04-02 Adição dos .stl das tampas dos rolos
    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
    [Tampa_Rolo_Motor_Esteira_Rolante_SOE.stl, Tampa_Rolo_Rolamento_esteira_rolante_SOE.stl]
2026-04-02 Atualização da pasta Fotos
    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
    [Tampa_Rolo_Motor_Esteira_Rolante_SOE.CATPart, Tampa_Rolo_Motor_Esteira_Rolante_SOE.stl, Tampa_Rolo_Rolamento_esteira_rolante_SOE.CATPart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]
2026-04-02 .
    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
    [Apoio_Base_Esteira_Rolante_SOE.CATPart, Apoio_Base_Esteira_Rolante_SOE.stl, Suporte_Motor_Esteira_Rolante_SOE.CATPart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]
2026-04-02 Arquivos STL
    [Apoio_Base_Esteira_Rolante_SOE.stl, Suporte_Motor_Esteira_Rolante_SOE.stl, Suporte_Parafuso_Esteira_Rolante_SOE.stl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]
2026-04-06 Teste do gerador de QR code e atualização da pasta fotos
    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
2026-04-07 Adicionando 10 peças
    Adicionadas 10 peças .catPART projetadas:
    - Cancela_servo: estrutura fixada ao eixo do servo motor para guiar objetos à saída B
    - Suporte_Servo: fixação do servo motor sobre a mesa da esteira
    - Suporte_STlink: fixação do programador/debugger STM32 no corpo da esteira
    - Suporte_laser_c_ajuste_focal (x3): suporte do laser com ajuste focal para alinhamento ao LDR
    - Suporte_LDR (x3): suporte do LDR para alinhamento ao laser na mesa
    - Suporte_laser_Rampa (x1): fixação do laser na lateral da rampa
    - Suporte_LDR_sensor_Rampa: suporte do LDR na lateral da rampa, alinhado ao laser
    - Suporte_flash_esteira (x2): suporte para fita de LED na região de leitura do QR
    - Supo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
    [Cancela_servo.CATPart, Suporte_LDR.CATPart, Suporte_LDR_sensor_Rampa.CATPart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]
2026-04-07 Adicionadas as duas ultimas peças da estrutura base da esteira
    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
    [Apoio_Base_Esteira_Rolante_SOE.CATPart, Lateral_esq_rampa_esteira_rolante_SOE.CATPart, Lateral_esq_rampa_esteira_rolante_SOE.stl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]
2026-04-07 STLs
    Adicionando os STLs
    [Cancela_servo.stl, Suporte_LDR.CATPart, Suporte_LDR.stl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]
2026-04-11 Teste do sensor laser
    Fotografias relacionadas ao teste do sensor laser realizado dia 10/04/2026. Os testes concluem que o sensor funciona como o esperado, agora é necessário que se realize a montagem de um módulo com qua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
2026-04-17 Remoção das fotos e inclusão da descrição das peças
    As fotos foram removidas e serão transferidas para um repositório maior como o google Drive. Isso será necessário pois o GitHub possui um limite máximo de arquivos a serem enviados por repositório, e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
2026-04-17 Remoção de atalhos desnecessários
    o putty e o vncviewer precisam estar instalados localmente para funcionar
2026-04-17 Atualização da pasta de entrega do PC1
    Inclusão do arquivo PDF enviado para avaliação
2026-04-23 Case RBPi3
    [raspberry_pi_4_mesh_case_with_fan_hole_and_GPIO_hole.3mf]
2026-05-05 Atualização GUI python
    Essa versão está preparada para controlar o firmware v3 do STM32G070, e contém uma janela mais completa para o debug e demonstração das funcionalidades locais do sistema
2026-05-05 Adição da interface da esteira
    Sistema da esteira separadora integrando GUI em Tkinter com comunicação serial entre STM32G070 microcontroller e Raspberry Pi 3B, adicionando leitura de QR Code com OpenCV/Pillow, parser flexível de 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
2026-05-06 Atualizações para firmware v3
    Atualização da interface gráfica e inclusão de pasta legacy, que concatena os arquivos antigos compactados em formato .zip
2026-05-06 Update para suporte em linux arm e linux x64
2026-05-07 Adicionando os arquivos da entrega do documento do ponto de controle 2
2026-05-08 Preparação para envio do PC2
    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
2026-05-15 Aula sobre IA
    Tomara que o Diogo abra esse monte de pasta
2026-06-12 Organização para entrega PC3
2026-06-12 Esquemático atualizado para o uso do PWM nos LEDs
2026-06-27 docs(pc4): adiciona LCD 2004, botões START/STOP e UART direta
    Hardware:
    - Substitui conversor UART-USB por ligação direta via /dev/ttyS0
    - Adiciona seção do LCD 2004 (PCF8574, I²C) e botões SW1/SW2 (CD4093)
    - Adiciona esquemático de pinagem do Raspberry Pi 3B (EasyEDA)
    - Adiciona tabela de mapeamento GPIO de 40 pinos
    - Atualiza BOM: +LCD, +CD4093, +botões, +resistores (total R$193,40)
    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
2026-07-07 Adição do suporte do display LCD
    [Suporte_display_botoes_SOE.CATPart, Suporte_display_botoes_SOE.stl]
